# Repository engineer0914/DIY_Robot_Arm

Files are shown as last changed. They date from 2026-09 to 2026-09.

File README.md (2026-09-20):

## 3D 프린팅으로 제작 및 제어하는 DIY 로봇팔 프로젝트

<div align="center">
  <!-- 프로젝트 로고 이미지가 있다면 아래 텍스트(h1) 대신 이미지(img) 태그를 사용하세요 -->
  <h1> 🤖 DIY Robot Arm Project </h1>
  
  <p>저비용 고효율 다관절 로봇팔 자체 제작 및 제어 프로젝트</p>

  <!-- 뱃지 모음 -->
  <p>
    
    
    
    
    
  </p>
</div>

<br>

## 출처

로봇팔: https://www.thingiverse.com/thing:1718984

기어박스: https://www.thingiverse.com/thing:8460

기어: https://www.thingiverse.com/thing:3364646

<div align="center">
  <video src="doc/assembly_vid.mp4" width="600" controls></video>
</div>

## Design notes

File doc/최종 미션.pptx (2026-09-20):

## 그리퍼 형태

- 최종 미션: 지우개를 옮겨라
- 1. 종이컵 -> 지상 녹색 지대내로 이송
- 2. 종이컵은 움직이면 안된다.

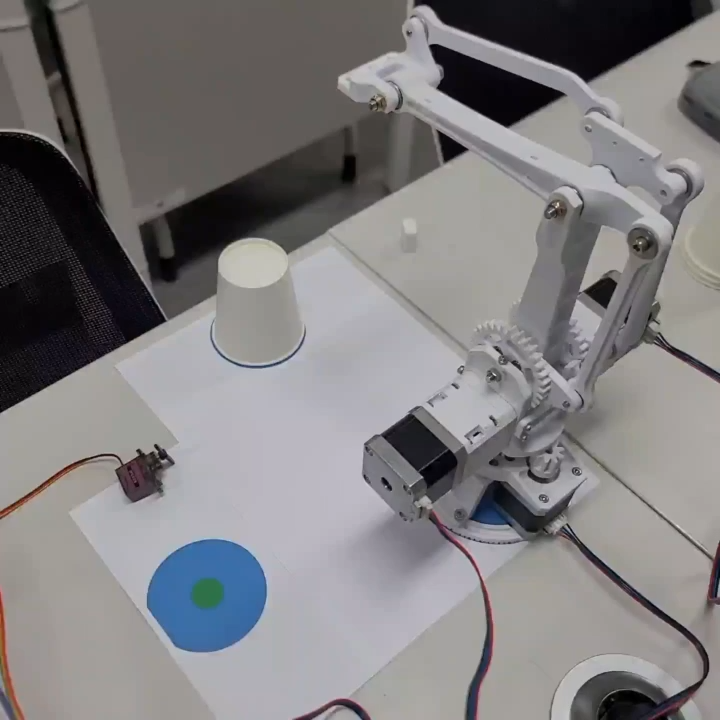
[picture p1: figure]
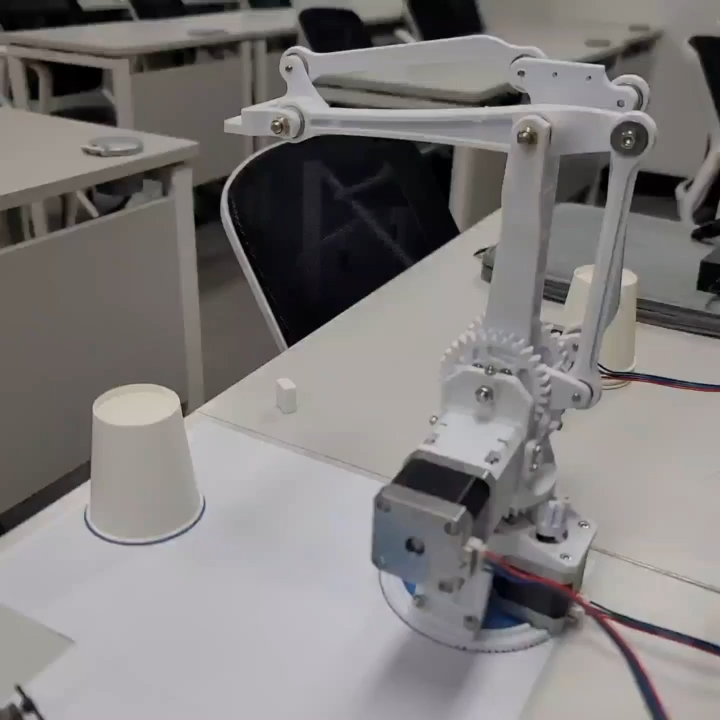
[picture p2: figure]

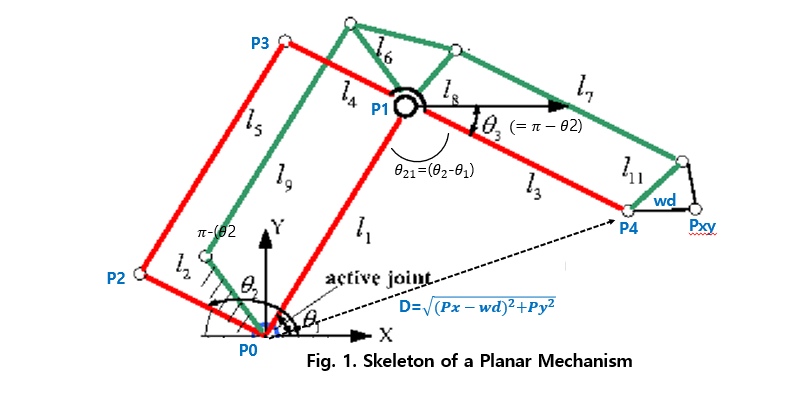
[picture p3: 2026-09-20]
doc/로봇팔 역기구학.png

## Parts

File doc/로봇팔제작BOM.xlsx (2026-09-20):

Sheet: 원본
품명 | 규격 | 수량
프린트 | 바디_접지링 | 1
 | 바디_그라운드 | 1
 | 바디_메인바디 | 1
 | 바디_지지대 | 3
 | 바디_프론트가드 | 1
 | 바디_비하인드가드 | 1
 | 바디_엔드이펙터 | 1
 | 바디_암 | 1
 | 바디_붐 | 1
 | 링크_엔드이펙터컨트롤 | 1
 | 링크_암컨트롤 | 1
 | 링크_암 | 2
 | 링크_붐 | 1
 | 기어_모터_너트(2개 여분) | 5
 | 기어_붐암 | 2
 | 기어_바디 | 1
 | 가이드 | 2
 | 선기어 | 2
 | 케이지 | 2
 | 페이스 | 2
 | 플래닛기어 | 6 | 링크 | 세트 | 표기된 가격
볼트(스텐) | M3(mm)
 | 무두 8 | 10 | https://smartstore.naver.com/boltoutlet/products/3900520395 | 100:1set | 1000
 | 8 | 28 | https://smartstore.naver.com/boltoutlet/products/3567551552 | 100:1set | 1000
 | 12 | 4 |  | 100:1set | 1000
 | 15 | 6 |  | 50:1set | 1000
 | 20 | 8 |  | 50:1set | 1000
 | M4
 | 10 | 6 |  | 50:1set | 1000
 | 15 | 12 |  | 50:1set | 1500
 | M5
 | 45 | 3 |  | 20:1set | 1400
 | 60 | 1 |  | 5:1set | 1600
 | 육각 30 | 2 | https://smartstore.naver.com/boltoutlet/products/4410669973 | 20:1set | 1000
너트(스텐) | M3 | 12 | https://smartstore.naver.com/boltoutlet/products/7063871164 | - | 20
 | M4 | 6 |  | - | 20
 | M3 나일론 | 6 | https://smartstore.naver.com/boltoutlet/products/6990469009 | - | 20
 | M5 나일론 | 4 |  | - | 10
와셔(스텐) | M4 | 12 | https://smartstore.naver.com/boltoutlet/products/3510200845 | 50:1set | 500
 | M5 | 24 |  | 50:1set | 500
 | M4-대형 15 | 10 | https://smartstore.naver.com/boltoutlet/products/3678003117 | 100:1set | 3200
 | M5-대형 15 | 18 |  | 100:1set | 2200
베어링 | 51105(25-42-11) | 1 | https://smartstore.naver.com/allbearing/products/443034914 | - | 3600
베어링 | 695ZZ(5-13-4) | 18 | https://smartstore.naver.com/allbearing/products/415759727 | - | 1500
베어링 | 624ZZ(4-13-5) | 6 |  | - | 1700
베어링 | 683ZZ | 12 |  | - | 1700
베어링 | F695ZZ | 1 | https://www.devicemart.co.kr/goods/view?no=1241387 | - | 3190
스텝모터 | NEMA17 | 3 | https://www.11st.co.kr/products/2475047432?NaPm=ct=l75roit4|ci=f932db0520310e3065b7ae57756678b3c8c51ea6|tr=slct|sn=17703|hk=cb1d047cef103bcc1c7613dbf667e2ce9bfb09c4&utm_term=&utm_campaign=%B3%D7%C0%CC%B9%F6pc_%B0%A1%B0%DD%BA%F1%B1%B3%B1%E2%BA%BB&utm_source=%B3%D7%C0%CC%B9%F6_PC_PCS&utm_medium=%B0%A1%B0%DD%BA%F1%B1%B3 | - | 8700
아두이노 | MEGA | 1 | https://www.devicemart.co.kr/goods/view?no=34405 | - | 58300
아두이노 선 | USB B | 1 | https://www.devicemart.co.kr/goods/view?no=1330154 | - | 990
모터 드라이브 | A4988 | 5(필수3개+여유분2개) | https://www.devicemart.co.kr/goods/view?no=1327610 | - | 1980
드라이브 보드 | A4988 쉴드 보드 | 1 | https://www.devicemart.co.kr/goods/view?no=1361492 | - | 2200
점퍼캡 | 2.54 | 9 | https://www.devicemart.co.kr/goods/view?no=1077104 | 5:1set | 220
파워서플라이 | 12V | 1 | https://www.devicemart.co.kr/goods/view?no=21792 | - | 18700
배럴잭 | - | 1 | https://www.devicemart.co.kr/goods/view?no=1065012 | - | 2420
핀헤더 | - | 2 | https://www.devicemart.co.kr/goods/view?no=20009 | 40:1set | 275
푸시락 버튼 | - | 1 | https://www.devicemart.co.kr/goods/view?no=10826175 | - | 2530
8버튼 | - | 1 | https://www.devicemart.co.kr/goods/view?no=1384067 | - | 7150
전선 | 암수 | 10가닥 | https://www.devicemart.co.kr/goods/view?no=1321195 | 40:1set(가닥) | 935 | 몇 개 남은가 | 필수 부품인가
배송비 | 디바이스마트 |  |  |  | 2700
 | 볼트 |  |  |  | 2500
 | 베어링 |  |  |  | 3500

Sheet: 10단위 올림표
품명 | 규격 | 수량
프린트 | 바디_접지링 | 1
 | 바디_그라운드 | 1
 | 바디_메인바디 | 1
 | 바디_지지대 | 3
 | 바디_프론트가드 | 1
 | 바디_비하인드가드 | 1
 | 바디_엔드이펙터 | 1
 | 바디_암 | 1
 | 바디_붐 | 1
 | 링크_엔드이펙터컨트롤 | 1
 | 링크_암컨트롤 | 1
 | 링크_암 | 1
 | 링크_붐 | 2
 | 기어_모터_너트(2개 여분) | 5
 | 기어_붐암 | 2
 | 기어_바디 | 1
 | 가이드 | 2
 | 선기어 | 2
 | 케이지 | 2
 | 페이스 | 2
 | 플래닛기어 | 6 | 링크 | 세트 | 표기된 가격
볼트(스텐) | M3(mm)
 | 무두 8 | 10 | https://smartstore.naver.com/boltoutlet/products/3900520395 | 100:1set | 1000
 | 8 | 30 | https://smartstore.naver.com/boltoutlet/products/3567551552 | 100:1set | 1000
 | 12 | 10 |  | 100:1set | 1000
 | 15 | 10 |  | 50:1set | 1000
 | 20 | 10 |  | 50:1set | 1000
 | M4
 | 10 | 10 |  | 50:1set | 1000
 | 15 | 20 |  | 50:1set | 1500
 | M5
 | 45 | 10 |  | 20:1set | 1400
 | 60 | 10 |  | 5:1set | 1600
 | 육각 30 | 10 | https://smartstore.naver.com/boltoutlet/products/4410669973 | 20:1set | 1000
너트(스텐) | M3 | 30 | https://smartstore.naver.com/boltoutlet/products/7063871164 | - | 20
 | M4 | 10 |  | - | 20
 | M3 나일론 | 10 | https://smartstore.naver.com/boltoutlet/products/6990469009 | - | 20
 | M5 나일론 | 10 |  | - | 10
와셔(스텐) | M4 | 20 | https://smartstore.naver.com/boltoutlet/products/3510200845 | 50:1set | 500
 | M5 | 30 |  | 50:1set | 500
 | M4-대형 15 | 10 | https://smartstore.naver.com/boltoutlet/products/3678003117 | 100:1set | 3200
 | M5-대형 15 | 20 |  | 100:1set | 2200
베어링 | 51105(25-42-11) | 1 | https://smartstore.naver.com/allbearing/products/443034914 | - | 3600
베어링 | 695ZZ(5-13-4) | 18 | https://smartstore.naver.com/allbearing/products/415759727 | - | 1500
베어링 | 624ZZ(4-13-5) | 6 |  | - | 1700
베어링 | 683ZZ | 12 |  | - | 1700
베어링 | F695ZZ | 1 | https://www.devicemart.co.kr/goods/view?no=1241387 | - | 3190
스텝모터 | NEMA17 | 3 | https://www.11st.co.kr/products/2475047432?NaPm=ct=l75roit4|ci=f932db0520310e3065b7ae57756678b3c8c51ea6|tr=slct|sn=17703|hk=cb1d047cef103bcc1c7613dbf667e2ce9bfb09c4&utm_term=&utm_campaign=%B3%D7%C0%CC%B9%F6pc_%B0%A1%B0%DD%BA%F1%B1%B3%B1%E2%BA%BB&utm_source=%B3%D7%C0%CC%B9%F6_PC_PCS&utm_medium=%B0%A1%B0%DD%BA%F1%B1%B3 | - | 8700
아두이노 | MEGA | 1 | https://www.devicemart.co.kr/goods/view?no=34405 | - | 58300
아두이노 선 | USB B | 1 | https://www.devicemart.co.kr/goods/view?no=1330154 | - | 990
모터 드라이브 | A4988 | 5 | https://www.devicemart.co.kr/goods/view?no=1327610 | - | 1980
드라이브 보드 | A4988 쉴드 보드 | 1 | https://www.devicemart.co.kr/goods/view?no=1361492 | - | 2200
점퍼캡 | 2.54 | 10 | https://www.devicemart.co.kr/goods/view?no=1077104 | 5:1set | 220
파워서플라이 | 12V | 1 | https://www.devicemart.co.kr/goods/view?no=21792 | - | 18700
배럴잭 | - | 1 | https://www.devicemart.co.kr/goods/view?no=1065012 | - | 2420
핀헤더 | - | 2 | https://www.devicemart.co.kr/goods/view?no=20009 | 40:1set | 275
푸시락 버튼 | - | 1 | https://www.devicemart.co.kr/goods/view?no=10826175 | - | 2530
8버튼 | - | 1 | https://www.devicemart.co.kr/goods/view?no=1384067 | - | 7150
전선 | 암수 | 13(가닥) | https://www.devicemart.co.kr/goods/view?no=1321195 | 40:1set(가닥) | 935
배송비 | 디바이스마트 |  |  |  | 2700
 | 볼트 |  |  |  | 2500
 | 베어링 |  |  |  | 3500

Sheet: 25년 가을 비교과 부품
비고 | 품명 | 규격 | 수량 | 5세트시 낱개 | 최종 구매 개수 | 링크 | 세트 | 부가세포함 1개 가격 | 총액 | 합산 금액 | 해외여부 | 활성화 | -
볼트 (SCM or 스텐) | M3(mm) |  |  |  |  |  |  |  |  |  |  | 0
 | 무두 8 |  | 10 | 50 | 50 | https://www.devicemart.co.kr/goods/view?no=10913620 | 10 | 33 | 330 | 1650 |  | 1
 | 8 |  | 30 | 150 | 150 | https://www.devicemart.co.kr/goods/view?no=34295 | 10 | 66 | 1980 | 9900 |  | 1
 | 12 |  | 10 | 50 | 50 | https://www.devicemart.co.kr/goods/view?no=10915194 | 10 | 66 | 660 | 3300 |  | 1
 | 15 |  | 10 | 50 | 50 | https://www.devicemart.co.kr/goods/view?no=10913623 | 10 | 44 | 440 | 2200 |  | 1 |  | 1414880 | 총액
 | 20 |  | 10 | 50 | 50 | https://www.devicemart.co.kr/goods/view?no=34536 | 10 | 66 | 660 | 3300 |  | 1
 | M4 |  |  | 0
 | 10 |  | 10 | 50 | 50 | https://www.devicemart.co.kr/goods/view?no=34496 | 10 | 55 | 550 | 2750 |  | 1 |  | 1500000 | 상한가
 | 15 |  | 20 | 100 | 100 | https://www.devicemart.co.kr/goods/view?no=34537 | 10 | 77 | 1540 | 7700 |  | 1
 | M5 |  |  | 0 |  |  |  |  |  |  |  | 1
 | 45 |  | 10 | 50 | 50 | https://www.devicemart.co.kr/goods/view?no=10915237 | 10 | 220 | 2200 | 11000 |  | 1
 | 60 |  | 10 | 50 | 50 | https://www.devicemart.co.kr/goods/view?no=10913873 | 10 | 320 | 3200 | 16000 |  | 1
 |  |  |  | 0
너트 (SCM or 스텐) | M3 |  | 30 | 150 | 150 | https://www.devicemart.co.kr/goods/view?no=34324 | 10 | 11 | 330 | 1650 |  | 1
 | M4 |  | 10 | 50 | 50 | https://www.devicemart.co.kr/goods/view?no=10893597 | 10 | 77 | 770 | 3850 |  | 1 |  | 육각 볼트 추가 배분 필요, 푸시락 버튼, 아두이노 쉴드
 | M3 나일론 |  | 10 | 50 | 50 | https://www.devicemart.co.kr/goods/view?no=34328 | 10 | 15.4 | 154 | 770 |  | 1
 | M5 나일론 |  | 10 | 50 | 50 | https://www.devicemart.co.kr/goods/view?no=34330 | 10 | 22 | 220 | 1100 |  | 1
와셔 (SCM or 스텐) | M4 |  | 20 | 100 | 2 | https://smartstore.naver.com/boltoutlet/products/3510200845 | 50:1set | 500 | 10000 | 1000 |  | 1
 | M5 |  | 30 | 150 | 3 |  | 50:1set | 500 | 15000 | 1500 |  | 1
 | M4-대형 15 |  | 10 | 50 | 1 | https://smartstore.naver.com/boltoutlet/products/3678003117 | 100:1set | 2200 | 22000 | 2200 |  | 1
 | M5-대형 15 |  | 20 | 100 | 1 |  | 100:1set | 2200 | 44000 | 2200 |  | 1
베어링 | 51105(25-42-11) |  | 1 | 5 | 5 | https://www.devicemart.co.kr/goods/view?no=1278300 | - | 4180 | 4180 | 20900 |  | 1
 | 695ZZ(5-13-4) |  | 18 | 90 | 90 | https://www.devicemart.co.kr/goods/view?no=1241341 | - | 1760 | 31680 | 158400 |  | 1
 | 624ZZ(4-13-5) |  | 6 | 30 | 30 | https://www.devicemart.co.kr/goods/view?no=1241334 | - | 1980 | 11880 | 59400 |  | 1
 | 683ZZ |  | 12 | 60 | 60 | https://www.devicemart.co.kr/goods/view?no=1241322 | - | 2090 | 25080 | 125400 |  | 1
 | F695ZZ |  | 1 | 5 | 5 | https://www.devicemart.co.kr/goods/view?no=1241387 | - | 3190 | 3190 | 15950 |  | 1
 |  |  |  | 0
 |  |  |  | 0
공구 | 롱노우즈 |  | 1 | 5 | 5 | https://www.devicemart.co.kr/goods/view?no=10991277 | - | 6160 | 6160 | 30800 |  | 1
 | 볼렌치 |  | 1 | 5 | 5 | https://www.devicemart.co.kr/goods/view?no=10991327 | - | 7700 | 7700 | 38500 |  | 1
 | 전동 드라이버 |  | 1 | 5 | 5 | https://www.devicemart.co.kr/goods/view?no=15018718 | - | 45430 | 45430 | 227150 |  | 1
스텝모터 | NEMA17 |  | 3 | 15 | 15 | https://www.11st.co.kr/products/2475047432?NaPm=ct=l75roit4|ci=f932db0520310e3065b7ae57756678b3c8c51ea6|tr=slct|sn=17703|hk=cb1d047cef103bcc1c7613dbf667e2ce9bfb09c4&utm_term=&utm_campaign=%B3%D7%C0%CC%B9%F6pc_%B0%A1%B0%DD%BA%F1%B1%B3%B1%E2%BA%BB&utm_source=%B3%D7%C0%CC%B9%F6_PC_PCS&utm_medium=%B0%A1%B0%DD%BA%F1%B1%B3 | - | 8700 | 26100 | 130500 |  | 1
아두이노 | MEGA |  | 1 | 5 | 5 | https://www.devicemart.co.kr/goods/view?no=34405 | - | 59400 | 59400 | 297000 |  | 1
아두이노 USB 선 | USB B |  | 1 | 5 | 5 | https://www.devicemart.co.kr/goods/view?no=1063725 | - | 1870 | 1870 | 9350 |  | 1
모터 드라이브 | A4988 |  | 4 | 20 | 20 | https://www.devicemart.co.kr/goods/view?no=1327610 | - | 1980 | 7920 | 39600 |  | 1
드라이브 보드 | A4988 쉴드 보드 |  | 1 | 5 | 5 | https://www.devicemart.co.kr/goods/view?no=1361492 | - | 2200 | 2200 | 11000 |  | 1
점퍼캡 | 2.54 |  | 10 | 50 | 50 | https://www.devicemart.co.kr/goods/view?no=1077104 | 5:1set | 44 | 440 | 2200 |  | 1
파워서플라이 | 12V |  | 1 | 5 | 5 | https://www.devicemart.co.kr/goods/view?no=21792 | - | 20900 | 20900 | 104500 |  | 1
배럴잭 | - |  | 1 | 5 | 5 | https://www.devicemart.co.kr/goods/view?no=1065012 | - | 2420 | 2420 | 12100 |  | 1
8버튼 | - |  | 1 | 5 | 1 | https://www.devicemart.co.kr/goods/view?no=1384067 | - | 7150 | 7150 | 7150 |  | 1
전선 | 암수 |  | 1 | 5 | 3 | https://www.devicemart.co.kr/goods/view?no=1321195 | 40:1set(가닥) | 935 | 935 | 2805 |  | 1
 | 암암 |  | 1 | 5 | 3 | https://www.devicemart.co.kr/goods/view?no=1321196 | 40:1set(가닥) | 935 | 935 | 2805 |  | 1
 | 수수 |  | 1 | 5 | 3 | https://www.devicemart.co.kr/goods/view?no=1321192 | 40:1set(가닥) | 935 | 935 | 2805 |  | 1
핀헤더 | - |  | 1 | 5 | 1 | https://www.devicemart.co.kr/goods/view?no=20009 | 40:1set | 275 | 275 | 275 |  | 1
스텝모터 연결선 여분 |  |  | 3 | 15 | 15 | https://www.devicemart.co.kr/goods/view?no=10893116 | - | 1100 | 3300 | 16500 |  | 1
서보모터 | mg90 |  | 1 | 5 | 6 | https://www.devicemart.co.kr/goods/view?no=1313389 | - | 4620 | 4620 | 27720 |  | 1

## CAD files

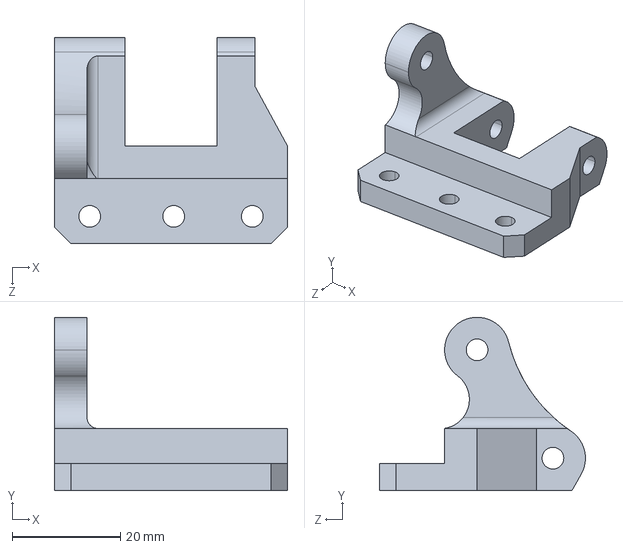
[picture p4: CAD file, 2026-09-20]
CAD/바디_엔드이펙터.STEP
43.0 x 32.0 x 38.0 mm

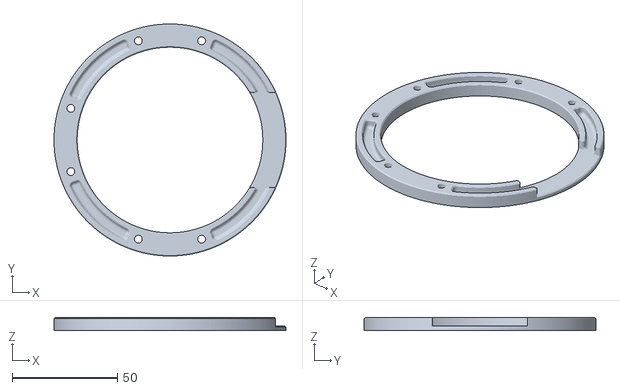
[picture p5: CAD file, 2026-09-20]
PrintFile/[ARM][1pcs] baseRing 바디_접지링.stl
110.0 x 110.0 x 6.00

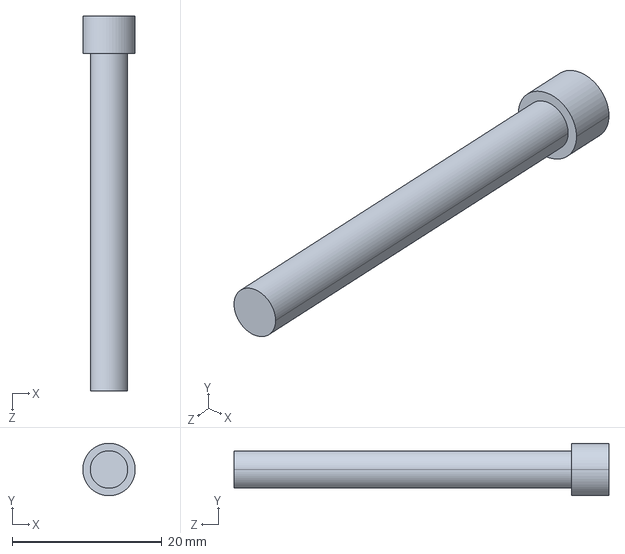
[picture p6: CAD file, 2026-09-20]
CAD/볼트 m5 45.STEP
7.00 x 7.00 x 50.0 mm

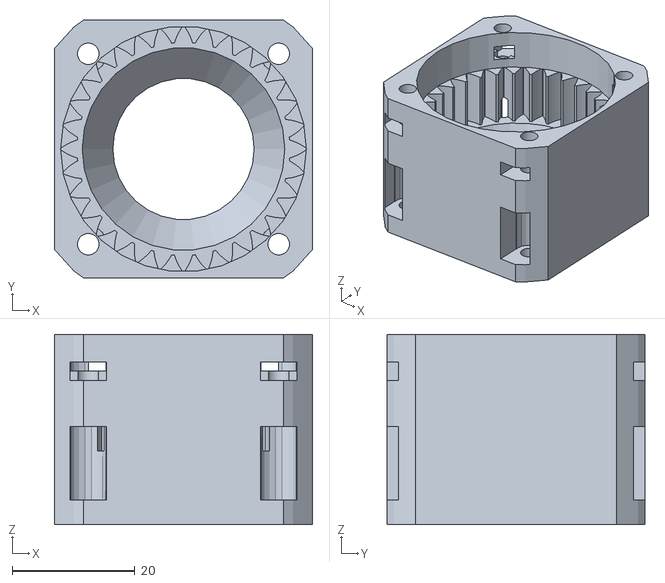
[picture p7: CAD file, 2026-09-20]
PrintFile/[REDUCER][2pcs] housing 케이지.stl
42.0 x 42.0 x 31.0

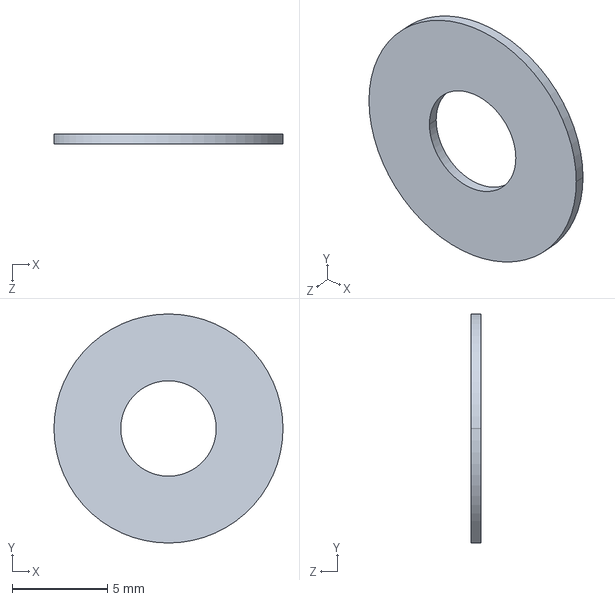
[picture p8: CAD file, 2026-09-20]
CAD/와셔 m5.STEP
12.0 x 12.0 x 0.5 mm

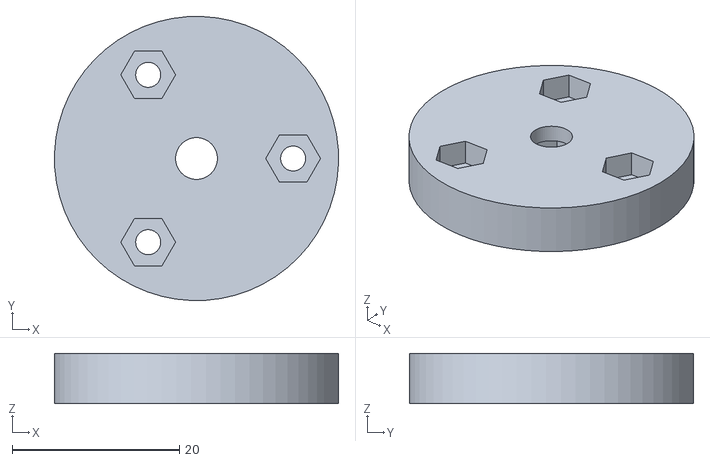
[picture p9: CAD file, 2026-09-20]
PrintFile/[REDUCER][2pcs] carrier 가이드.stl
34.0 x 34.0 x 6.00

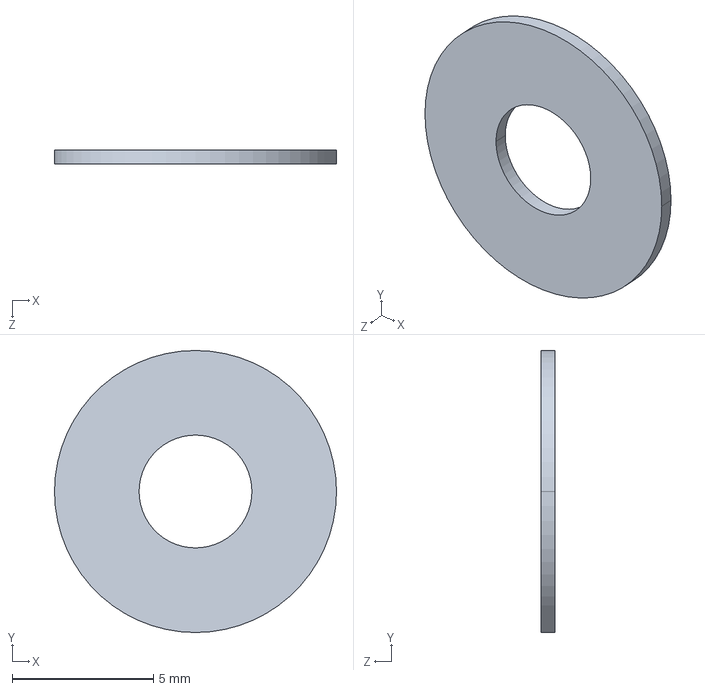
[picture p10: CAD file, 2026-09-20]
CAD/와셔 m4.STEP
10.0 x 10.0 x 0.5 mm

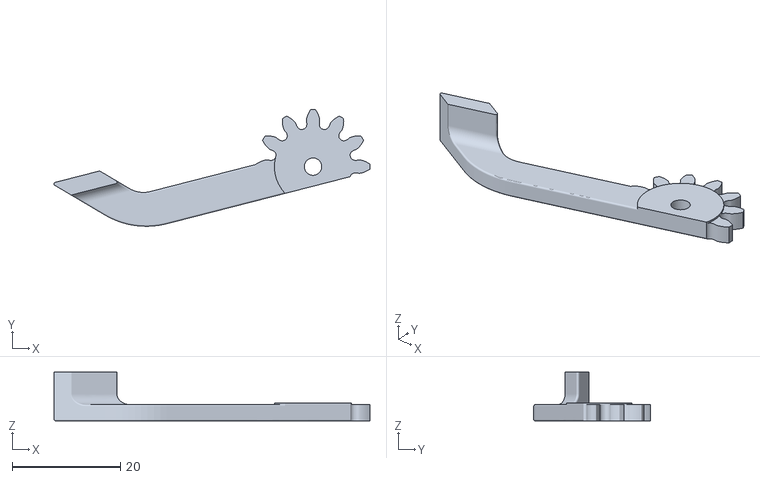
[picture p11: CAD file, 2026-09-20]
PrintFile/[sGripper][1pcs]EBAmk2_017_claw_finger_sx.STL
58.3 x 21.5 x 9.00

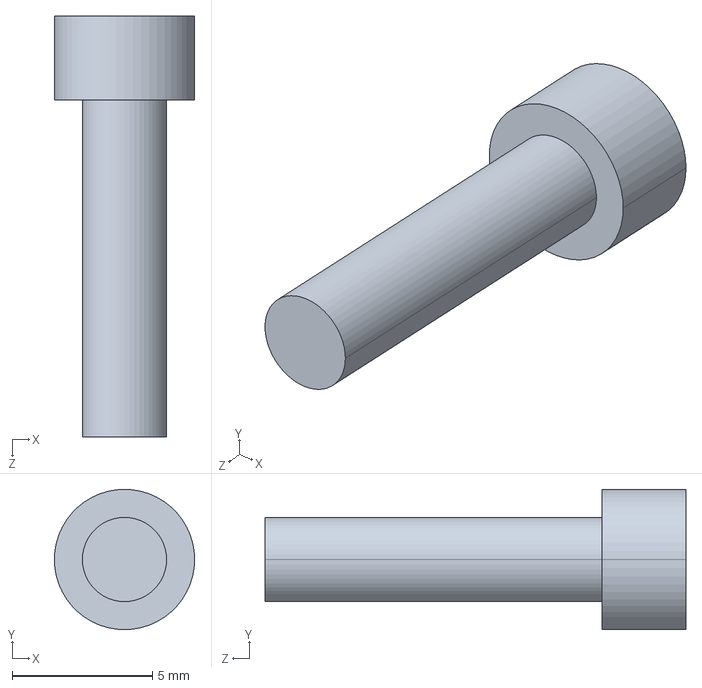
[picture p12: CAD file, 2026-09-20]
CAD/볼트 m3 12.STEP
5.00 x 5.00 x 15.0 mm

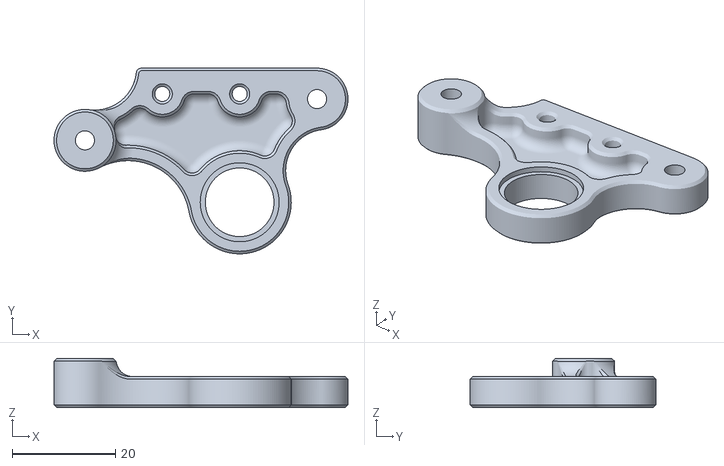
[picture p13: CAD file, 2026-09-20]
PrintFile/[ARM][1pcs] triplate 링크_엔드이펙터컨트롤.stl
57.0 x 36.0 x 9.50

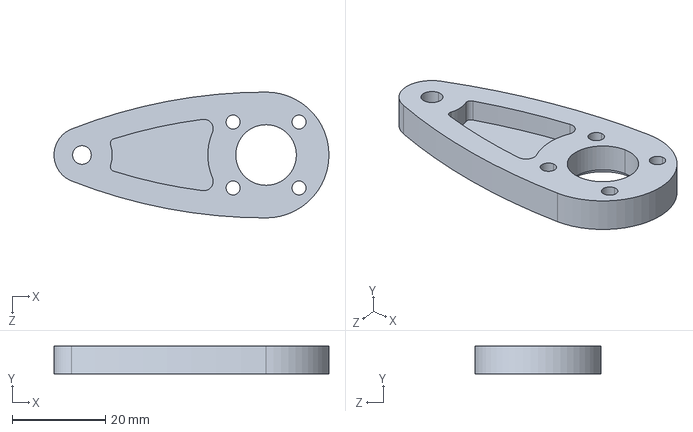
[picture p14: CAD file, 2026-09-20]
CAD/링크_암컨트롤.STEP
59.0 x 6.00 x 27.0 mm

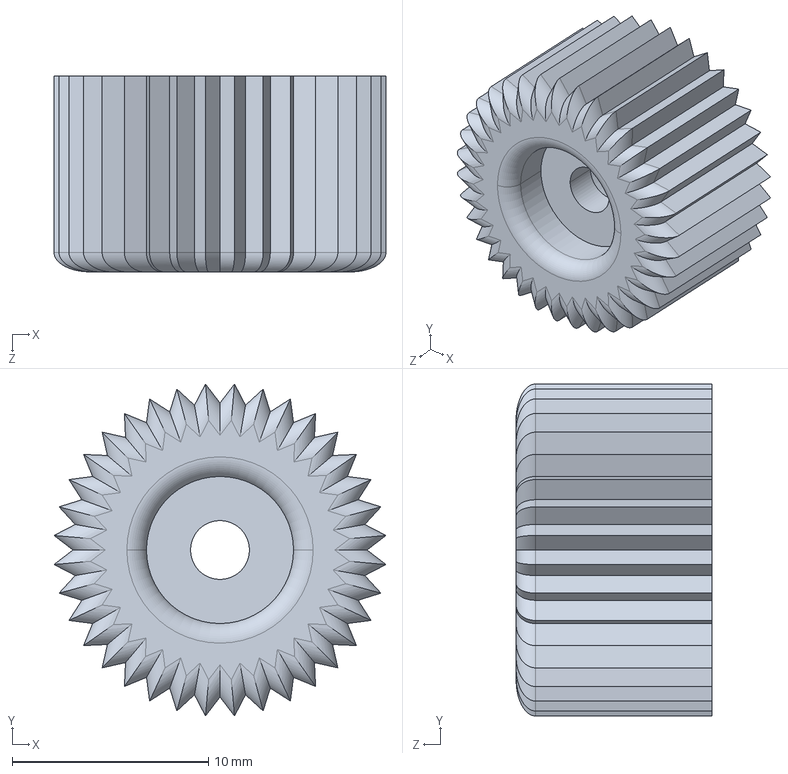
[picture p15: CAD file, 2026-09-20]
CAD/플래닛기어.STEP
16.9 x 16.9 x 10.0 mm

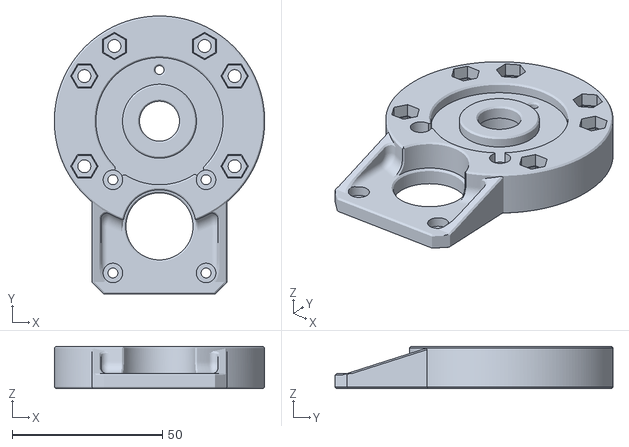
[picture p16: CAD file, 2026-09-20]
PrintFile/[ARM][1pcs] socket 바디_그라운드.stl
70.0 x 92.5 x 14.0

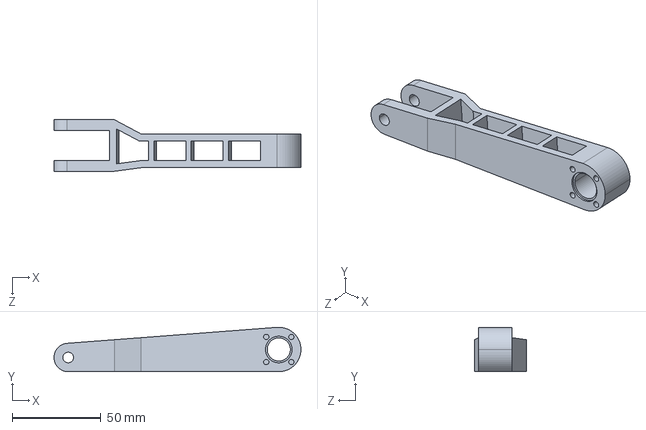
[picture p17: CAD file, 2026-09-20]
CAD/바디_붐.STEP
139.0 x 25.0 x 29.0 mm

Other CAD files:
PrintFile/[ARM][1pcs] GearRotate_0.01mmTolerance 기어_바디.stl
CAD/바디_접지링.STEP
PrintFile/[REDUCER][6pcs] planet 플래닛기어.stl
CAD/바디_메인바디.STEP
CAD/683zz 베어링.STEP
CAD/가이드.STEP
CAD/기어_모터.STEP
CAD/기어_바디.STEP
CAD/기어_붐암.STEP
CAD/나일론 m3 너트.STEP
CAD/너트 m3.STEP
CAD/너트 m4.STEP
CAD/너트 m5 나일론.STEP
CAD/링크_붐.STEP
CAD/링크_암.STEP
CAD/링크_엔드이펙터컨트롤.STEP
CAD/모터.STEP
CAD/무두나사 m3 8.STEP
CAD/바디_그라운드.STEP
CAD/바디_비하인드가드.STEP
CAD/바디_암.STEP
CAD/바디_지지대.STEP
CAD/바디_프론트가드.STEP
CAD/베어링 m4.STEP
CAD/베어링 m5.STEP
CAD/베어링 m5f.STEP
CAD/베어링 베이스.STEP
CAD/볼트 m3 15.STEP
CAD/볼트 m3 20.STEP
CAD/볼트 m3 8.STEP
CAD/볼트 m4 10.STEP
CAD/볼트 m4 15.STEP
CAD/볼트 m5 60.STEP
CAD/선기어.STEP
CAD/엔드이펙터 마커.STEP
CAD/와셔 m4 대형.STEP
CAD/와셔 m5 대형.STEP
CAD/육각볼트 m5 30.STEP
CAD/케이지.STEP
CAD/페이스.STEP
PrintFile/[ARM][1pcs] base_w_hole 바디_메인바디.stl
PrintFile/[ARM][1pcs] lever 링크_암컨트롤.stl
PrintFile/[ARM][1pcs] lowerShank 바디_붐.stl
PrintFile/[ARM][1pcs] pleuel 링크_붐.stl
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

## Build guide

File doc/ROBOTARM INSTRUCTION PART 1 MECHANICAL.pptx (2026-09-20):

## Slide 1

ROBOT ARM INSTRUCTION
PART.1 - MECHANICAL

Prof. Wooyong Kim
Assistant. Dongsik Park
Department of Biomedical & Robotics Engineering,
Incheon National University

Summer, 2026

## Table of Contents

  1. List Of Part
  2. Building Instruction

## 1. List Of Part

3D Print

Part name | Number
바디_접지링 | 1
바디_그라운드 | 1
바디_메인바디 | 1
바디_지지대 | 3
바디_프론트가드 | 1
바디_비하인드가드 | 1
바디_엔드이펙터 | 1
바디_암 | 1
바디_붐 | 1
링크_엔드이펙터컨트롤 | 1
링크_암컨트롤 | 1
링크_암 | 1
링크_붐 | 2
기어_모터_너트(2개 여분) | 5
기어_붐암 | 2
기어_바디 | 1
가이드 | 2
선기어 | 2
케이지 | 2
페이스 | 2
플래닛기어 | 6

Mechanical Material

(Need) hex key(육각렌치) – 1.5, 3, 4, 5 mm

Part name | Number
M3 8 무두 | 10
M3 8 | 28
M3 12 | 4
M3 15 | 6
M3 20 | 8
M4 10 | 6
M4 15 | 12
M5 45 | 3
M5 60 | 1
M5 30 육각 | 2
M3 너트 | 22
M4 너트 | 6
M3 나일론 너트 | 6
M5 나일론 너트 | 4
M4 와셔 | 12
M5 와셔 | 24
M4 와셔 대형 | 8
M5 와셔 대형 | 20
베어링 51105(25-42-11) | 1
베어링 695ZZ(5-13-4) | 18
베어링 624ZZ(4-13-5) | 6
베어링 683ZZ | 12
베어링 F695ZZ | 1

Circuit Material

(Need) Phillips screwdriver (십자드라이버)

Part name | Number
스텝모터 | 3
아두이노 메가 | 1
A4988 드라이버 | 3
드라이브 보드 | 1
점퍼캡 | 9
파워서플라이 | 1
배럴잭 | 1
핀헤더 | 2
푸시락 버튼 | 1
8버튼 | 1
전선 | 13

## 1. List Of Part

3D Print & Body parts look

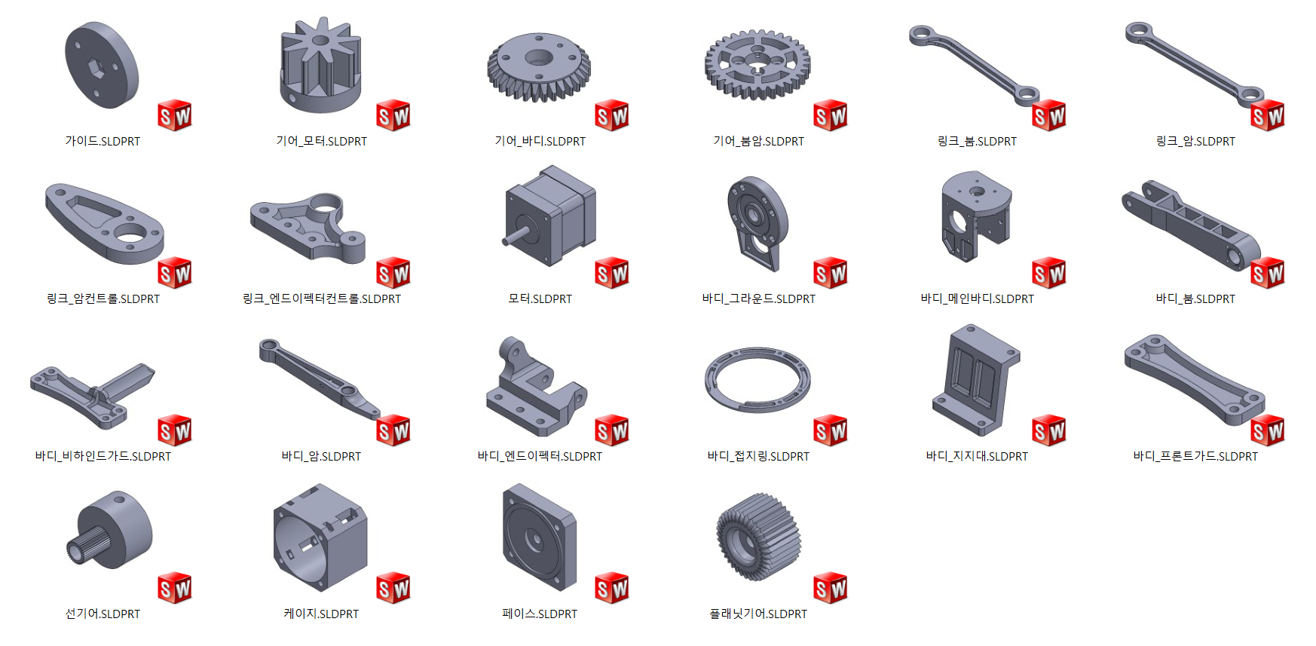
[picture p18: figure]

가이드

기어_모터_너트

기어_바디

기어_붐암

링크_암

링크_붐

링크_암컨트롤

링크_엔드이펙터컨트롤

스텝모터

바디_그라운드

바디_메인바디

바디_붐

바디_비하인드가드

바디_암

바디_엔드이펙터

바디_접지링

바디_지지대

바디_프론트가드

선기어

케이지

페이스

플래닛기어

## 2. Building Instruction

Base

Part name | Count
M4 10mm | 6
M4 15mm | 6
M4 너트 | 6

Required Parts

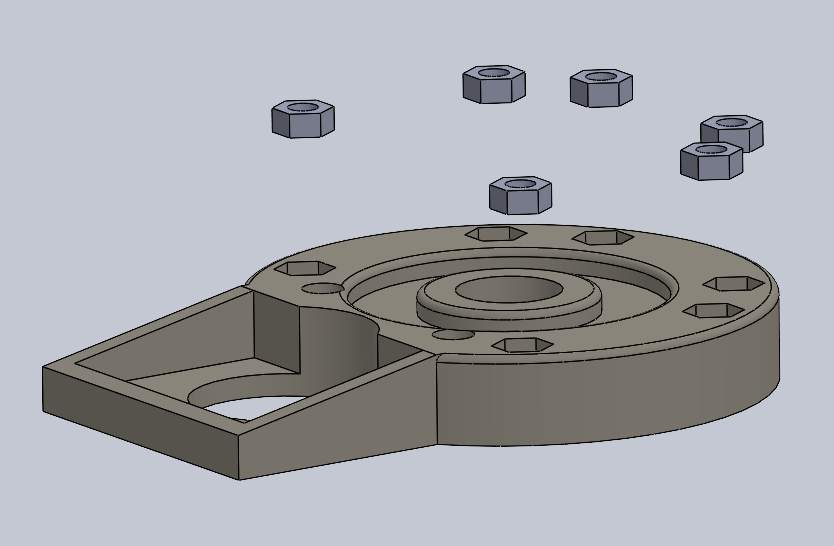
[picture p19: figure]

10mm

15mm

## 2. Building Instruction

Base

Part name | Count
M3 8mm (무두) | 2
M3 8mm | 4
M3 너트 | 2
베어링 51105 | 1

Required Parts

무두 나사

베어링

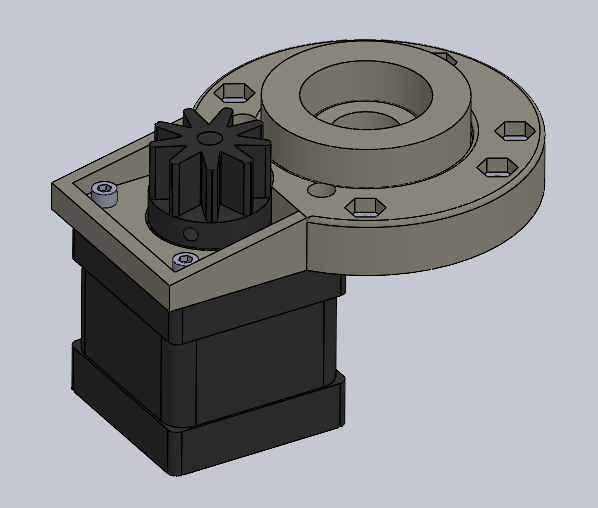
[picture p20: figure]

## 2. Building Instruction

Base

Part name | Count
M5 45mm | 1
M3 너트 | 4
M5 너트 (나일론) | 1
M5 와셔 (대형) | 4
베어링 F695ZZ | 1

Required Parts

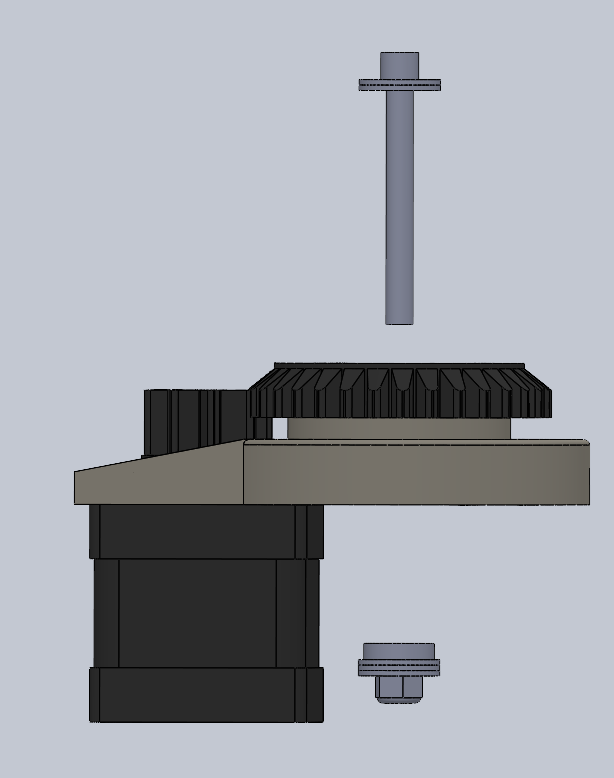
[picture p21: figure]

대형 와셔 X 2

베어링
대형 와셔 X 2
나일론 너트

## 2. Building Instruction

Base

## 2. Building Instruction

GearReducer

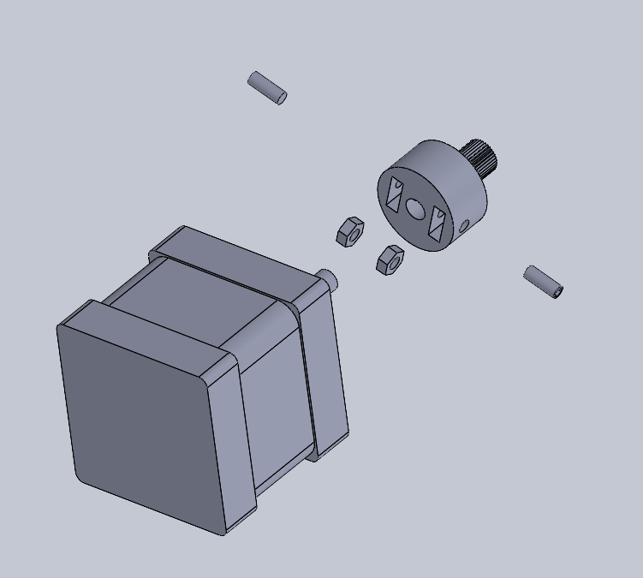
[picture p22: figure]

Part name | Count
M3 8mm (무두) | 2
M3 너트 | 2

Required Parts

무두 나사

## 2. Building Instruction

GearReducer

Part name | Count
M3 15mm | 3
M5 30mm (육각) | 1
M3 너트 (나일론) | 3
베어링 683ZZ (M3) | 6

Required Parts

베어링

15mm

나일론 너트

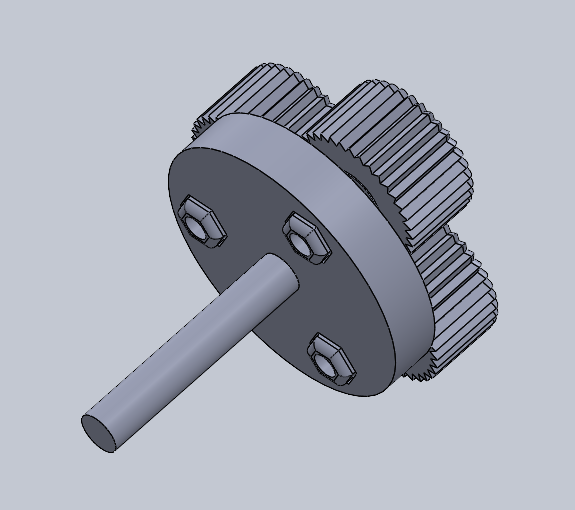
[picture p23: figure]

## 2. Building Instruction

GearReducer

Part name | Count
M3 8mm | 4
베어링 695ZZ (M5) | 2

Required Parts

베어링

베어링

## 2. Building Instruction

GearReducer

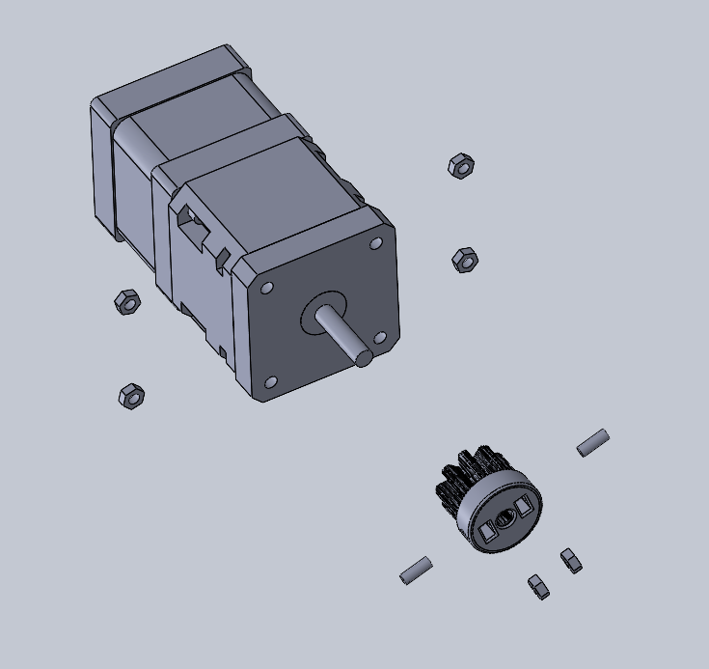
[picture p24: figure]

Part name | Count
M3 8mm (무두) | 2
M3 너트 | 6

Required Parts

무두 나사

## 2. Building Instruction

Body

Part name | Count
M3 20mm | 8

Required Parts

## 2. Building Instruction

Body

Part name | Count
M3 12mm | 4

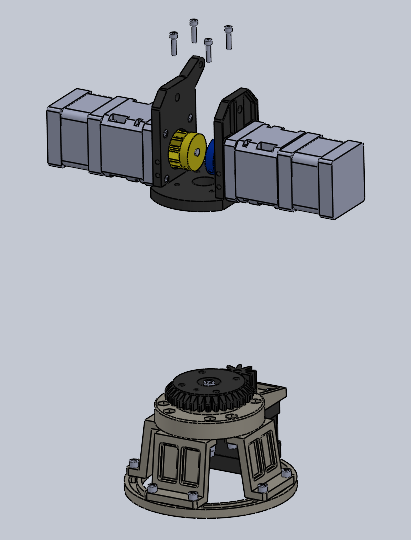
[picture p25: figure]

## 2. Building Instruction

Arm

Part name | Count
M5 45mm | 1
M5 너트 (나일론) | 1
M5 와셔 | 2
M5 와셔 (대형) | 4
베어링 695ZZ (M5) | 3

Required Parts

대형 와셔

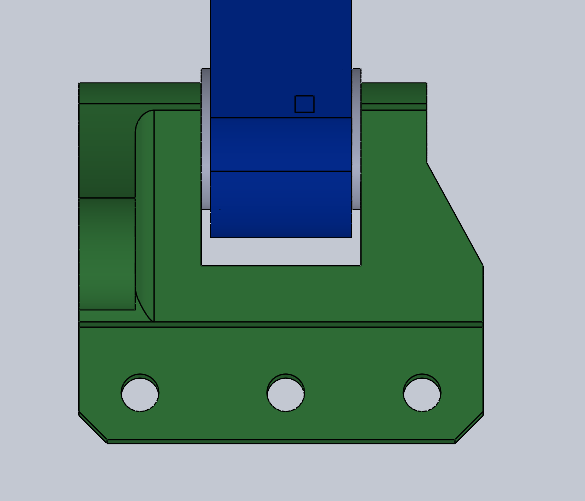
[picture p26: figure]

와셔

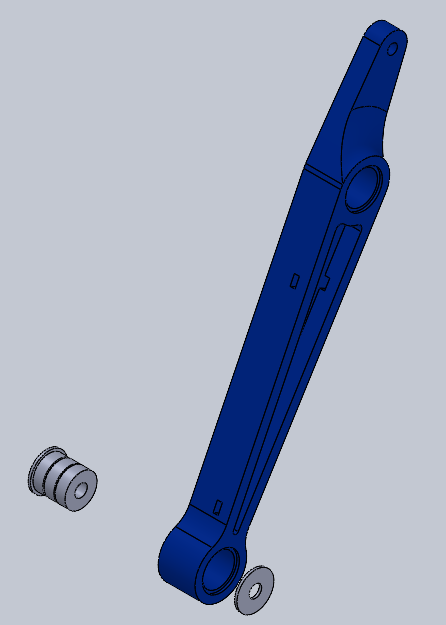
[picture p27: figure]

## 2. Building Instruction

Arm

Part name | Count
M5 45mm | 1
M5 와셔 | 2
M5 와셔 (대형) | 5
베어링 695ZZ (M5) | 3

Required Parts

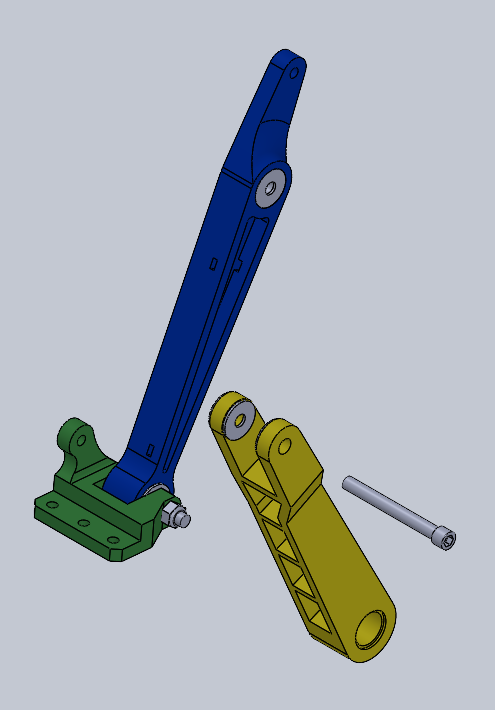
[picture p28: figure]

위치별 대형 와셔 개수: 2 2 1

와셔

## 2. Building Instruction

Arm

Part name | Count
M5 45mm | 1
M5 너트 (나일론) | 1
M5 와셔 | 4
M5 와셔 (대형) | 1
베어링 695ZZ (M5) | 1

Required Parts

대형 와셔

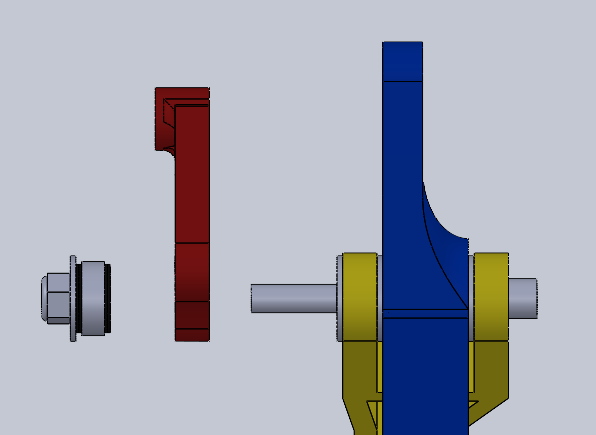
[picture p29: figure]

와셔 X2

## 2. Building Instruction

Arm

Part name | Count
M4 15mm | 2
M4 와셔 | 4
M4 와셔 (대형) | 4
베어링 624ZZ (M4) | 2

Required Parts

대형 와셔

와셔

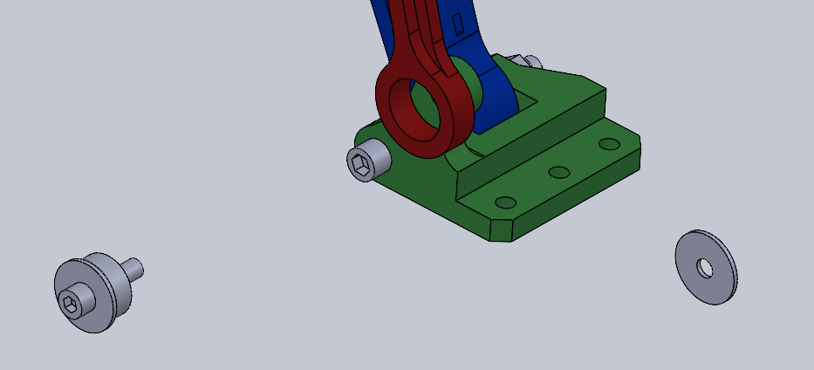
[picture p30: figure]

## 2. Building Instruction

Arm

Part name | Count
M4 15mm | 1
M4 와셔 | 2
M4 와셔 (대형) | 2
베어링 624ZZ (M4) | 1

Required Parts

대형 와셔

와셔

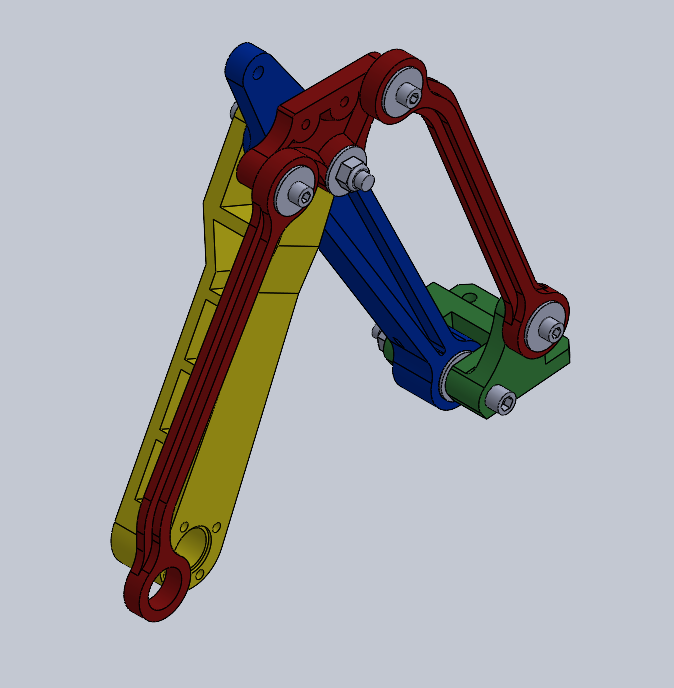
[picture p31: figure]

## 2. Building Instruction

Arm

Part name | Count
M4 15mm | 1
M4 와셔 | 2
M4 와셔 (대형) | 2
베어링 624ZZ (M4) | 1

Required Parts

대형 와셔

와셔

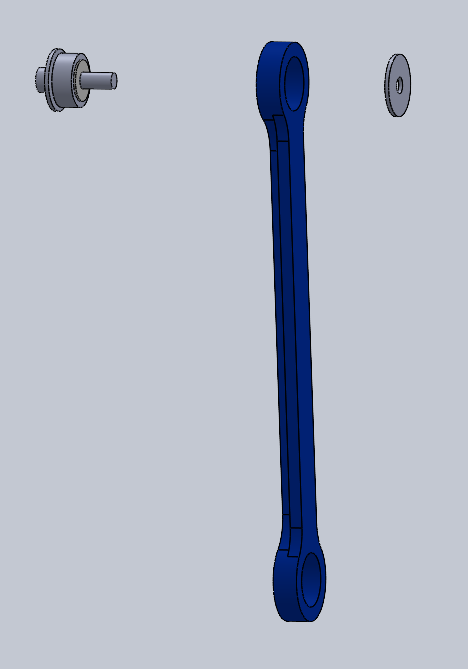
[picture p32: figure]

## 2. Building Instruction

Arm

Part name | Count
M5 와셔 | 2
M5 와셔 (대형) | 2
베어링 695ZZ (M5) | 4

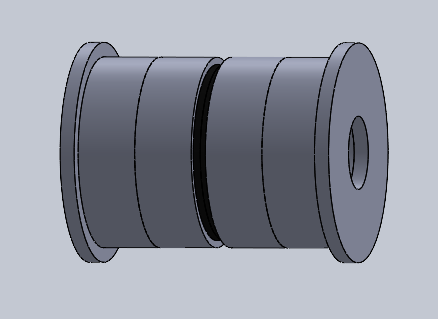
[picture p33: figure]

대형 와셔

와셔 X2

## 2. Building Instruction

Part name | Count
M3 8mm | 8
M5 와셔 | 14 (9/5)
M5 와셔 (대형) | 2
베어링 695ZZ (M5) | 3

Required Parts

Arm

대형 와셔

위치별 와셔 개수: 1 2 4 2

위치별 와셔 개수: 2 2 1

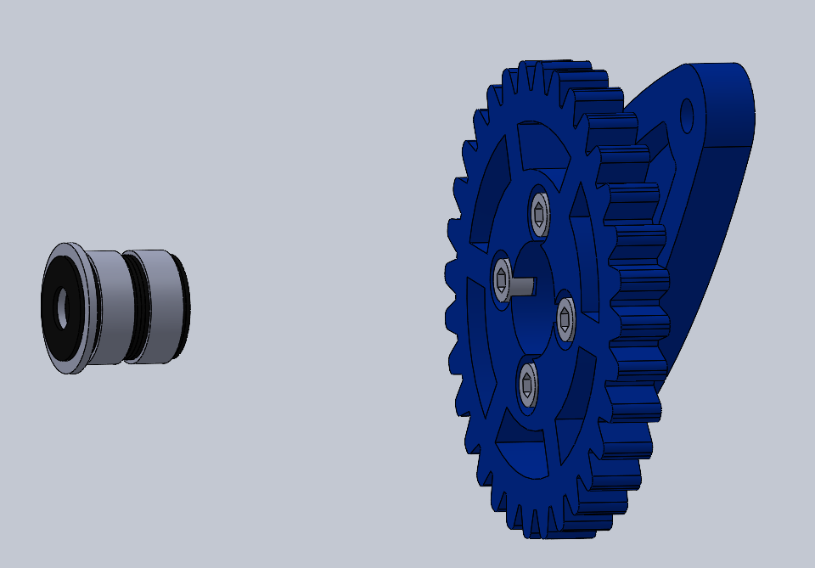
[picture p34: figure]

## 2. Building Instruction

Arm

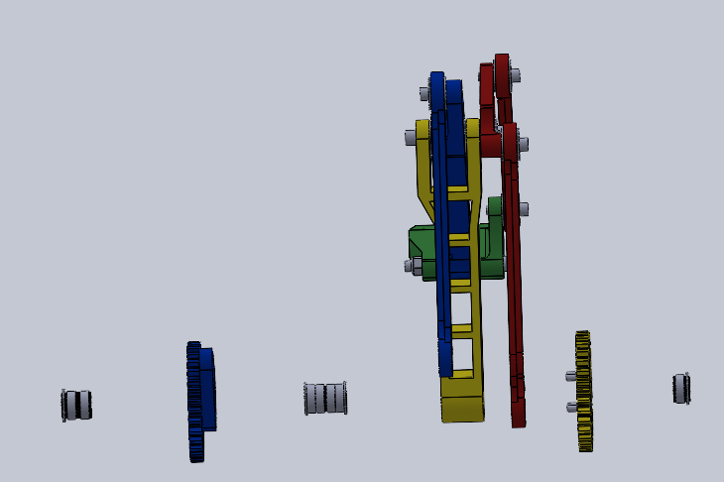
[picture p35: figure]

## 2. Building Instruction

Final assembly

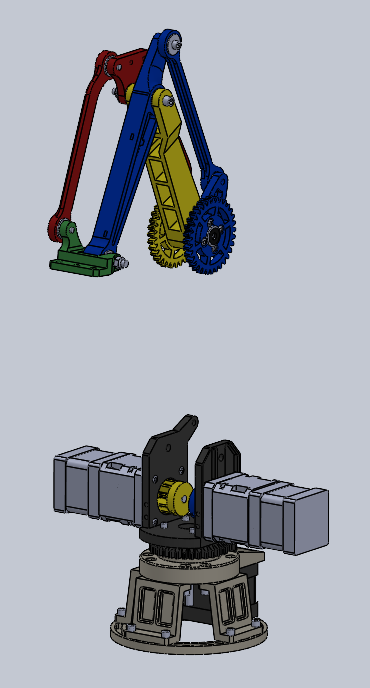
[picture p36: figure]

## 2. Building Instruction

Final assembly

Part name | Count
M5 60mm | 1
M5 너트 (나일론) | 1

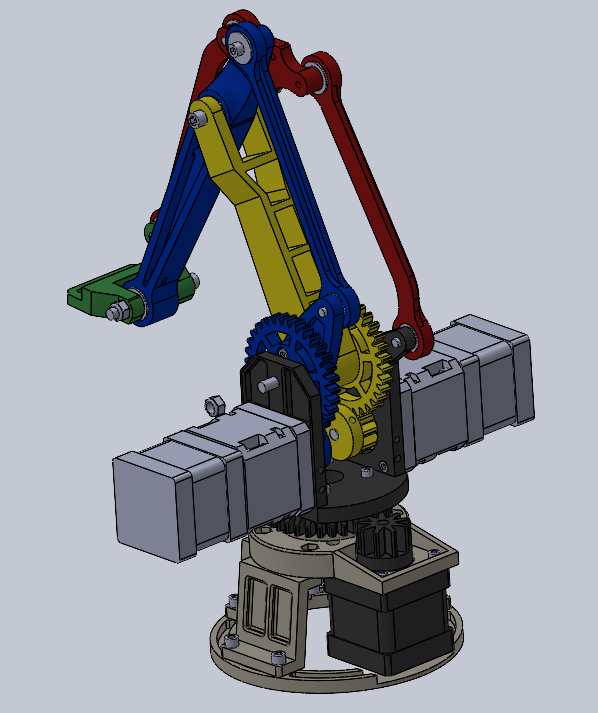
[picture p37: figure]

## 2. Building Instruction

Final assembly

Part name | Count
M4 15mm | 2
M4 와셔 | 4
M4 와셔 (대형) | 2
베어링 624ZZ (M4) | 2

대형 와셔

와셔

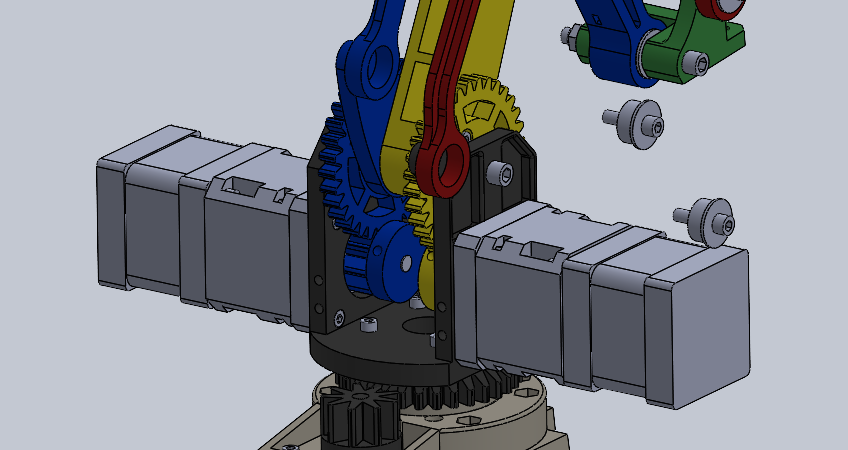
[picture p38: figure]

## 2. Building Instruction

Final assembly

Part name | Count
M3 8mm | 8

Required Parts

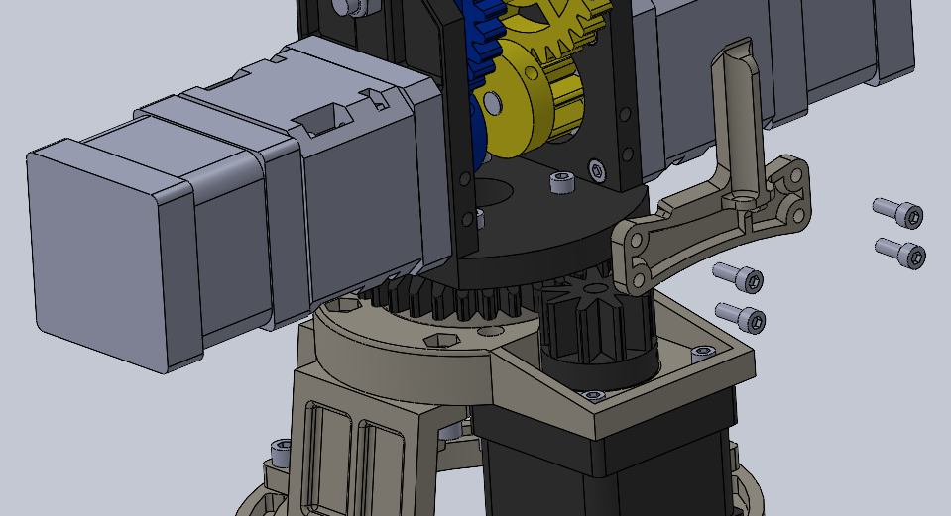
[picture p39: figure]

## 2. Building Instruction

Final assembly

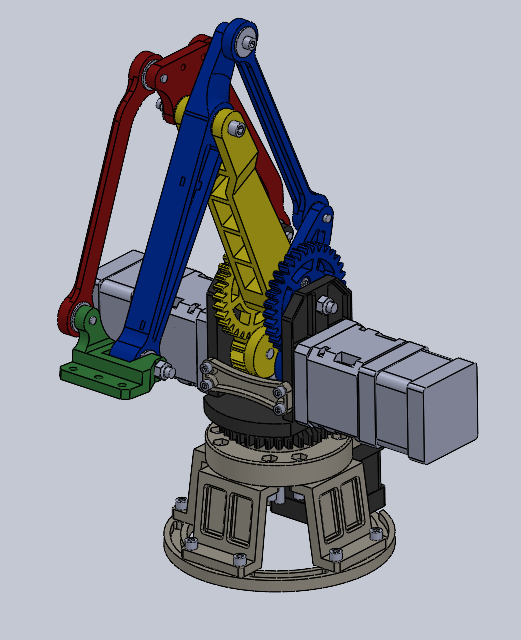
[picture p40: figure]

## 그리퍼 형태

- 볼트 M3 : 15, 10
- 나일론 너트 M3 1

https://www.thingiverse.com/thing:4812073
https://www.thingiverse.com/thing:1454048

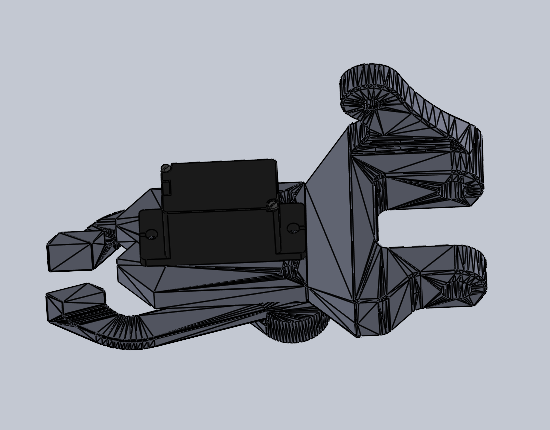
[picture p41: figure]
스케치, 그림이(가) 표시된 사진 AI 생성 콘텐츠는 정확하지 않을 수 있습니다.

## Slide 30

Thanks.

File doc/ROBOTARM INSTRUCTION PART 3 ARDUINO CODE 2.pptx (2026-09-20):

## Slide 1

ROBOT ARM INSTRUCTION
PART.3 – ARDUINO CODE

Prof. Wooyong Kim
Assistant. Dongsik Park
Department of Biomedical & Robotics Engineering,
Incheon National University

Summer, 2026

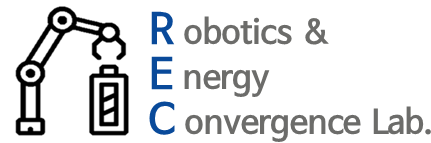
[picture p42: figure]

## Table of Contents

  1. learning objectives – Forward Kinematics
  2. Forward Kinematics needs
  3. Direction of control practice
  4. Stepper motor
  5. Stepper motor action & Angle input action
  6. Gear ratio calculate
  7. Current angle check
  8. Forward Kinematics
  9. Inverse Kinematics
  10. How to design

## learning objectives – Forward Kinematics

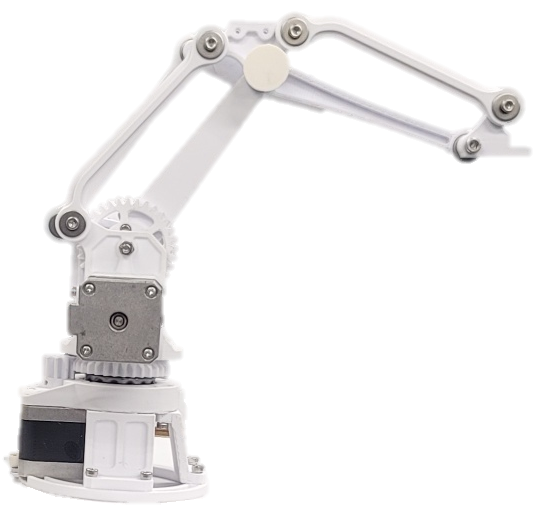
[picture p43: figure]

INPUT: ANGLE OUTPUT: COORDINATE
B_x =L_1 sin(θ_1 )
B_y =L_1 cos(θ_1 )
A_x =B_x +L_3 cos(θ_3 )
A_y =B_y −L_3 sin(θ_3 )
E_x =A_x +wd
E_y =A_y

B_x ,B_y

θ_3

L_3

wd

E_x ,E_y

L_1

A_x ,A_y

θ_1

## Forward Kinematics needs

INPUT: ANGLE OUTPUT: COORDINATE
B_x =L_1 sin(θ_1 )
B_y =L_1 cos(θ_1 )
A_x =B_x +L_3 cos(θ_3 )
A_y =B_y −L_3 sin(θ_3 )
E_x =A_x +wd
E_y =A_y

B_x ,B_y

θ_3

L_3

wd

E_x ,E_y

L_1

A_x ,A_y

θ_1

Trigonometric coordinate

Motor angle control

Current angle check

Gear ratio calculation

## Direction of control practice

1. Manipulator should be operated using manual control code instead of backdrive
2. SDK for additional function queries

SDK

https://www.airspayce.com/mikem/arduino/AccelStepper/classAccelStepper.html

## Stepper motor

VIDEO

https://www.youtube.com/watch?v=09Mpkjcr0bo&t=188s

## Stepper motor action & angle input action

void loop()
{
rotationmovementinsert(3200,0,0)
anglemovementinset(360,0,0);//붐 30도 이동
}
void rotationmovementinsert(long base,long boom,long arm)
{
//0~3200사이 값을 입력 받아 스텝값으로 저장(마이크로 스텝은 16배인 3200)
positions[robot_position_base] = base;
positions[robot_position_arm] = arm;
positions[robot_position_boom] = boom;
steppers.moveTo(positions); //포지션 입력
steppers.runSpeedToPosition(); //각각 동작
}

## Stepper motor action & angle input action

void anglemovementinset(double angle_base, double angle_boom, double angle_arm)
{
double instantbo, instantba, instantar;//지역 변수 선언
//베이스의 경우 감속기어가 없이 평기어만 부착되어있음에 원하는 각도에 따라 요구되는 스텝수 계산 수식
//1.스텝모터 1회전(360도)시 요구되는 스텝 = 200, (1스텝당 1.8도 이동)
//2.마이크로 스텝 설정시, 스텝 2,4,8,16배 증폭가능, 16배 증폭에 따라 스텝모터 1회전시 요구되는 스텝 = 200*16
//3.원하는 각도 입력시 상응하는 스텝수 계산식 = (angle/360)*200*16
instantba = (angle_base*microstep/360);
instantbo = (angle_base*microstep/360);
instantar = (angle_base*microstep/360);
//4.계산된 스텝값 인자로 입력, 이때, 스텝수는 long 형이고 현재는 세밀한 계산을 위해 형변환 입력
rotationmovementinsert((long)instantba, (long)instantbo, (long)instantar);
}

## Gear ratio calculate

- Gear Teeth Count & Form SUN gear : 8 - INPUT PLANET gear : 12 - OUTPUT RING gear : 32 - HOLD
- Formular : 1+r/s=1+(32/8)=5

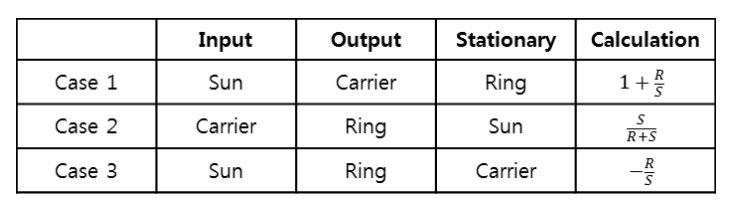
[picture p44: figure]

## Gear ratio calculate

void anglemovementinset(double angle_base, double angle_boom, double angle_arm)
{
double instantbo, instantba, instantar;//지역 변수 선언
//1.스텝모터 1회전(360도)시 요구되는 스텝 = 200, (1스텝당 1.8도 이동)
//2.마이크로 스텝 설정시, 스텝 2,4,8,16배 증폭가능, 스텝모터 1회전시 스텝 = 200*16
//3.평기어 기어비 = 32/9(3.56)임에따라 평기어 1회전시 스텝 = 200*16*3.56
//4.추가적으로 5:1감속기어가 부착, 감속기어 1회전 스텝수 = 200*16*3.56*5
//5.원하는 감속기어 각도 입력시 이에 상응하는 스텝수 계산식 = (angle/360)*200*16*3.56*5
instantba = (angle_base*microstep/360);
instantbo = (planetarygear*angle_boom*smallgearstep*microstep*normgear/360);
instantar = (planetarygear*angle_arm*smallgearstep*microstep*normgear/360);
rotationmovementinsert((long)instantba, (long)instantbo, (long)instantar);
}

## Current angle check

void currentpositionshower()//현재 각도를 출력하는 함수
{
long instantshower;//지역변수
instantshower = base.currentPosition();//프로그램 내부적으로 베이스 모터의 현재 스텝 값을 읽어옴
baseangle_current = (double)instantshower*360/(smallgearstep*microstep*normgear);//기어비 계산후 저장
Serial.print("\nangle current base:");
Serial.println(baseangle_current);//각도 출력
instantshower = boom.currentPosition();
boomangle_current = (double)instantshower*360/(smallgearstep*microstep*planetarygear*normgear);//감속기어 부착
Serial.print("angle current boom:");
Serial.println(boomangle_current);
instantshower = arm.currentPosition();
armangle_current = (double)instantshower*360/(smallgearstep*microstep*planetarygear*normgear);
Serial.print("angle current arm:");
Serial.println(armangle_current);
}

## Forward Kinematics

INPUT: ANGLE OUTPUT: COORDINATE
B_x =L_1 sin(θ_1 )
B_y =L_1 cos(θ_1 )
A_x =B_x +L_3 cos(θ_3 )
A_y =B_y −L_3 sin(θ_3 )
E_x =A_x +wd
E_y =A_y

B_x ,B_y

θ_3

L_3

wd

E_x ,E_y

L_1

A_x ,A_y

θ_1

## Forward Kinematics

void Foward_Kinematics_Action(double input_base,double input_boom,double input_arm)
{
Foward_Kinematics_Calculator(input_base,input_boom,input_arm);//입력 각도에 따른 좌표 계산
anglemovementinset(input_base,input_boom,input_arm);//각도 입력 및 이동
currentpositionshower();//현재 좌표 출력
}
void Foward_Kinematics_Calculator(double angle_base, double angle_boom, double angle_arm)
{
//double boom_L1 = 12.0;//boom의 길이
//double arm_L3 = 12.0;//arm의 길이
//double endeffectoroffset_wd = 3.0;//arm의 끝과 엔드이펙터 사이의 거리
angle_arm = radians(angle_arm);//입력 각도 도 -> 라디안 변환
angle_boom = radians(angle_boom);//입력 각도 도 -> 라디안 변환
double x_boom = boom_L1*sin(angle_boom);//붐의 끝부분 평면 좌표 x축 = sin(붐 각도)*붐 길이
double y_boom = boom_L1*cos(angle_boom)+y_offset;//붐의 끝부분 평면 좌표 y축 = cos(붐 각도)*붐 길이 + 본체 높이 오프셋 길이
double x_arm = x_boom+(arm_L3*cos(angle_arm));//암의 끝부분 평면 좌표 x축 = cos(암각도)*암 길이 + 붐 x좌표
double y_arm = y_boom-(arm_L3*sin(angle_arm));//암의 끝부분 평면 좌표 y축 = sin(암각도)*암 길이*-1 + 붐 y좌표()세타 3가 기준이라 반대로 이동
double x_end = x_arm+endeffectoroffset_wd;//최종 좌표 + 엔드이펙터 오프셋 거리
double y_end = y_arm;//최종 좌표
}

## Inverse Kinematics

A

c

b

a

1. second hyperbolic law of cosines
a^2 =b^2 +c^2 −2bccos(A)
(−a^2 +b^2 +c^2)/(2bc)=cos(A)
acos((−a^2 +b^2 +c^2)/(2bc))=A° … ①

2. Pythagoras' theorem
a^2 =b^2 +c^2 … ②

c

a

b

## Inverse Kinematics

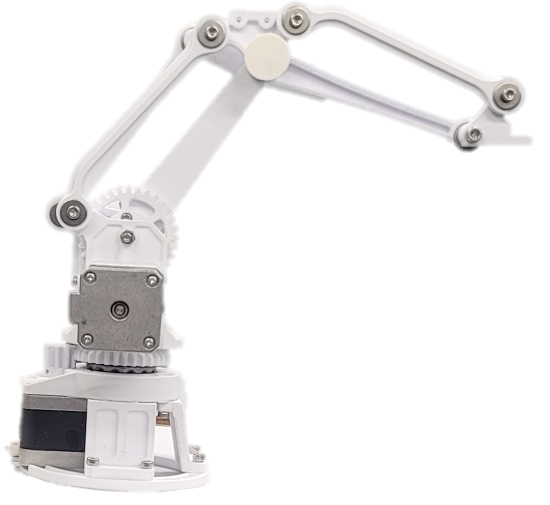
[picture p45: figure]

INPUT:COORDINATE OUTPUT:ANGLE
E_x =A_x +wd, E_y =A_y
D=√(A_x^2 +E_y^2) … ②
acos((L_1^2 +L_3^2 −D^2)/(2L_1 L_3))=θ_21 …①
acos((L_1^2 +D^2 −L_3^2)/(2L_1 D))=θ_α …①
acos((D^2 +(E_x −wd)^2 −E_y^2)/(2D(E_x −wd)))=θ_β …①
θ_γ ={, θ_α +θ_β , E_y ≥0, &θ_α −θ_β , E_y <0
θ_1 =90−θ_γ
θ_3 =180 −(θ_21 +θ_γ )

θ_γ

B_x ,B_y

θ_3

θ_21

L_3

wd

E_x ,E_y

L_1

A_x ,A_y

θ_3

θ_1

θ_α

θ_γ

D

θ_β

## Inverse Kinematics

INPUT:COORDINATE OUTPUT:ANGLE
E_x =A_x +wd, E_y =A_y
D=√(A_x^2 +E_y^2) … ②
acos((L_1^2 +L_3^2 −D^2)/(2L_1 L_3))=θ_21 …①
acos((L_1^2 +D^2 −L_3^2)/(2L_1 D))=θ_α …①
acos((D^2 +(E_x −wd)^2 −E_y^2)/(2D(E_x −wd)))=θ_β …①
θ_γ ={, θ_α +θ_β , E_y ≥0, &θ_α −θ_β , E_y <0
θ_1 =90−θ_γ
θ_3 =180 −(θ_21 +θ_γ )

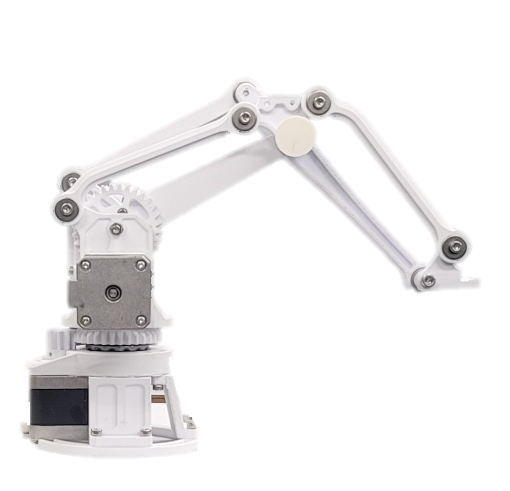
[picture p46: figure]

θ_γ

θ_21

θ_3

B_x ,B_y

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
A_x ,A_y

E_x ,E_y

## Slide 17

Inverse Kinematics

void Inverse_Kinematics_Calculator(double P_x, double P_y)
{
// double boomangle_th1, armangle_th2, th21, D, alpha, psi;
// y_offset, endeffectoroffset_wd, boom_L1, arm_L3
// P_x, P_y
double boomangle_th1, armangle_th2, th21, D, alpha, psi;
//1. 계산의 편의를 위해 엔드이펙터 관절부로 오프셋 차감 2 줄
P_y -= y_offset;//오프셋 제거
P_x -= endeffectoroffset_wd;//오프셋 제거
//2. 피타고라스 정리를 이용하여 D 계산 1 줄
D = sqrt(pow(P_x, 2) + pow(P_y, 2));//엔드이펙터 관절의 3차원 공간 위치
//3. 제2 코사인 법칙을 통해 붐과 암 사이 각(th21) 구하기 1 줄
th21 = acos((pow(boom_L1, 2) + pow(arm_L3, 2) - pow(D, 2)) / (2 * boom_L1 * arm_L3));
//4. 제2 코사인 법칙을 통해 D와 붐 사이 각(alpha) 구하기 1 줄
alpha = acos((pow(boom_L1, 2) + pow(D, 2) - pow(arm_L3, 2)) / (2 * boom_L1 * D));
//5. 제2 코사인 법칙을 통해 지면과 붐 사이 각(beta = psi) 구하기 1 줄
psi = acos((pow(D, 2) + pow(P_x, 2) - pow(P_y, 2)) / (2 * D * P_x));
}

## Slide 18

Inverse Kinematics

void Inverse_Kinematics_Calculator(double P_x, double P_y)
{
//6. 계산된 3개의 라디안 도 변환 (deg = rad*180/PI) 3 줄
alpha = degrees(alpha);
psi = degrees(psi);
th21 = degrees(th21);//붐 암 사이 각
//7. 붐 중앙축 y좌표 기준 엔드이펙터의 y좌표가 이상(alpha + psi)인지 이하(alpha - psi)별 수식 작성 = 붐 각도(boomangle_th1) 계산 2
if (P_y >= 0) boomangle_th1 = alpha + psi;//만약 엔드이펙터의 높이가 boom,arm 모터의 중심보다 위에 있을경우
else boomangle_th1 = alpha - psi;//만약 엔드이펙터의 높이가 boom,arm 모터의 중심보다 아래에 있을경우
//8. 사잇각(th21) + 붐 각도(boomangle_th1) = 암 각도(armangle_th2) 계산 1 줄
armangle_th2 = th21 + boomangle_th1; //암 모터 각도
//9. 모터에 맞는 기준축 간의 각도 값 변환((-1*boomangle_th1)+90, (-1*armangle_th2)+180 = out_boomangle, out_armangle) 2 줄
out_boomangle = (-1*boomangle_th1)+90;//오프셋 제외 최종 각도 붐
out_armangle = (-1*armangle_th2)+180;//오프셋 제외 최종 각도 암
}

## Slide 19

How to design

In order to put the desired action, created a separate function to put the code in performance_(1~6).
Practice
1. Write the desired action to the function (ex. performance_1) and upload it.
2. Modify the initial posture with the manual control button
3. Initialize with Arduino reset button
4. Enforce the desired action
5. Emergency stop in case of an abnormality in operation

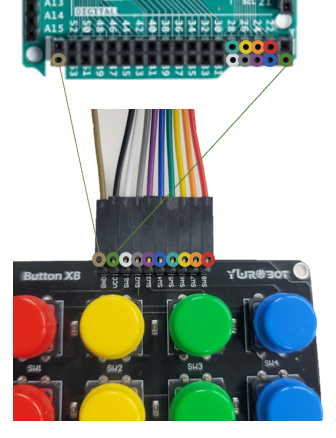
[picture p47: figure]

Bottom Blue button: button Angular manual control
Top blue button: Serial communication InverseKinematics manual control
(‘w,a,s,d' input in the serial window and moved, ‘q,e,f,g’ just setted.)
Bottom green button: performance_1
Top green button: performance_2
Bottom Yellow button: perfomance_3
Top Yellow button: perfomance_4
Bottom red button: perfomance_5
Top red button: perfomance_6

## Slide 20

Thanks.

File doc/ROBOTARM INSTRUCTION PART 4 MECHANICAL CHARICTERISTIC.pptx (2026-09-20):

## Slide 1

ROBOT ARM INSTRUCTION
PART.4 – MECHANICAL CHARACTERISTICS

Prof. Wooyong Kim
Assistant. Dongsik Park
Department of Biomedical & Robotics Engineering,
Incheon National University

Summer, 2026


## Table of Contents

  1. Planetary Gear
  2. Forward Kinematics
  3. Inverse Kinematics

## 1. Planetary Gear

Specific & Caculation

- Gear Teeth Count & Form SUN gear : 8 - INPUT PLANET gear : 12 - OUTPUT RING gear : 32 - HOLD
- Formular : 1+r/s=1+(32/8)=5


## 2. Forward Kinematics


INPUT: ANGLE OUTPUT: COORDINATE
B_x =L_1 sin(θ_1 )
B_y =L_1 cos(θ_1 )
A_x =B_x +L_3 cos(θ_3 )
A_y =B_y −L_3 sin(θ_3 )
E_x =A_x +wd
E_y =A_y

B_x ,B_y

θ_3

L_3

wd

E_x ,E_y

L_1

A_x ,A_y

θ_1

We convert angles to align with different reference points: in math, angles are counterclockwise from the x-axis, but in this robotic arm, angles like theta 1 and theta 3 are measured clockwise from specific lines.

## 3. Inverse Kinematics

A

c

b

a

1. second hyperbolic law of cosines
a^2 =b^2 +c^2 −2bccos(A)
(−a^2 +b^2 +c^2)/(2bc)=cos(A)
acos((−a^2 +b^2 +c^2)/(2bc))=A° … ①

2. Pythagoras' theorem
a^2 =b^2 +c^2 … ②

c

a

b

## 3. Inverse Kinematics


INPUT:COORDINATE OUTPUT:ANGLE
E_x =A_x +wd, E_y =A_y
D=√(A_x^2 +E_y^2) … ②
acos((L_1^2 +L_3^2 −D^2)/(2L_1 L_3))=θ_21 …①
acos((L_1^2 +D^2 −L_3^2)/(2L_1 D))=θ_α …①
acos((D^2 +(E_x −wd)^2 −E_y^2)/(2D(E_x −wd)))=θ_β …①
θ_γ ={, θ_α +θ_β , E_y ≥0, &θ_α −θ_β , E_y <0
θ_1 =90−θ_γ
θ_3 =180 −(θ_21 +θ_γ )

θ_γ

B_x ,B_y

θ_3

θ_21

L_3

wd

E_x ,E_y

L_1

A_x ,A_y

θ_3

θ_1

θ_α

θ_γ

D

θ_β

## 3. Inverse Kinematics

INPUT:COORDINATE OUTPUT:ANGLE
E_x =A_x +wd, E_y =A_y
D=√(A_x^2 +E_y^2) … ②
acos((L_1^2 +L_3^2 −D^2)/(2L_1 L_3))=θ_21 …①
acos((L_1^2 +D^2 −L_3^2)/(2L_1 D))=θ_α …①
acos((D^2 +(E_x −wd)^2 −E_y^2)/(2D(E_x −wd)))=θ_β …①
θ_γ ={, θ_α +θ_β , E_y ≥0, &θ_α −θ_β , E_y <0
θ_1 =90−θ_γ
θ_3 =180 −(θ_21 +θ_γ )


θ_γ

θ_21

θ_3

B_x ,B_y

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
A_x ,A_y

E_x ,E_y

## 4. Backlash caculate

Ey_x ,Ey_y =backlash minimum angle position
Eb_x ,Eb_x =backlash maximum angle position
backlash maximum angle −backlash minimum angle= θ_b =θ_1 +θ_2

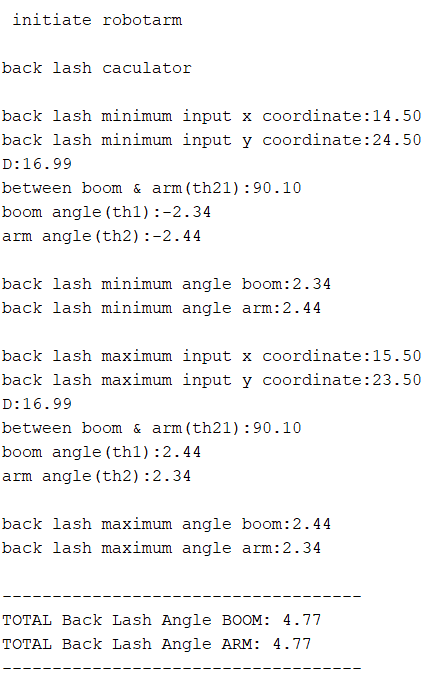
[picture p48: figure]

Eb_x ,Eb_y

θ_2

θ_1

D_b

D_y

Ey_x ,Ey_y

θ_b

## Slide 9

Thanks.

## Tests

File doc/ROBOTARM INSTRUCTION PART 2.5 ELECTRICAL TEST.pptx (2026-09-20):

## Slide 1

ROBOT ARM INSTRUCTION
PART.2 - ELECTRICAL

Prof. Wooyong Kim
Assistant. Dongsik Park
Department of Biomedical & Robotics Engineering,
Incheon National University

Summer, 2026


## Table of Contents

  1. List Of Part
  2. Circuit Diagram
  3. Wiring Diagram
  4. Detail connection
  5. ETC

## 1. List Of Part

3D Print

Part name | Number
바디_접지링 | 1
바디_그라운드 | 1
바디_메인바디 | 1
바디_지지대 | 3
바디_프론트가드 | 1
바디_비하인드가드 | 1
바디_엔드이펙터 | 1
바디_암 | 1
바디_붐 | 1
링크_엔드이펙터컨트롤 | 1
링크_암컨트롤 | 1
링크_암 | 1
링크_붐 | 2
기어_모터_너트(2개 여분) | 5
기어_붐암 | 2
기어_바디 | 1
가이드 | 2
선기어 | 2
케이지 | 2
페이스 | 2
플래닛기어 | 6

Mechanical Material

(Need) hex key(육각렌치) – 1.5, 3, 4, 5 mm

Part name | Number
M3 8 무두 | 10
M3 8 | 28
M3 12 | 4
M3 15 | 6
M3 20 | 8
M4 10 | 6
M4 15 | 12
M5 45 | 3
M5 60 | 1
M5 30 육각 | 2
M3 너트 | 22
M4 너트 | 6
M3 나일론 너트 | 6
M5 나일론 너트 | 4
M4 와셔 | 12
M5 와셔 | 24
M4 와셔 대형 | 8
M5 와셔 대형 | 20
베어링 51105(25-42-11) | 1
베어링 695ZZ(5-13-4) | 18
베어링 624ZZ(4-13-5) | 6
베어링 683ZZ | 12
베어링 F695ZZ | 1

Circuit Material

(Need) Phillips screwdriver (십자드라이버)

Part name | Number
스텝모터 | 3
아두이노 메가 | 1
A4988 드라이버 | 3
드라이브 보드 | 1
점퍼캡 | 9
파워서플라이 | 1
배럴잭 | 1
핀헤더 | 2
푸시락 버튼 | 1
8버튼 | 1
전선 | 13

## 2. Circuit Diagram

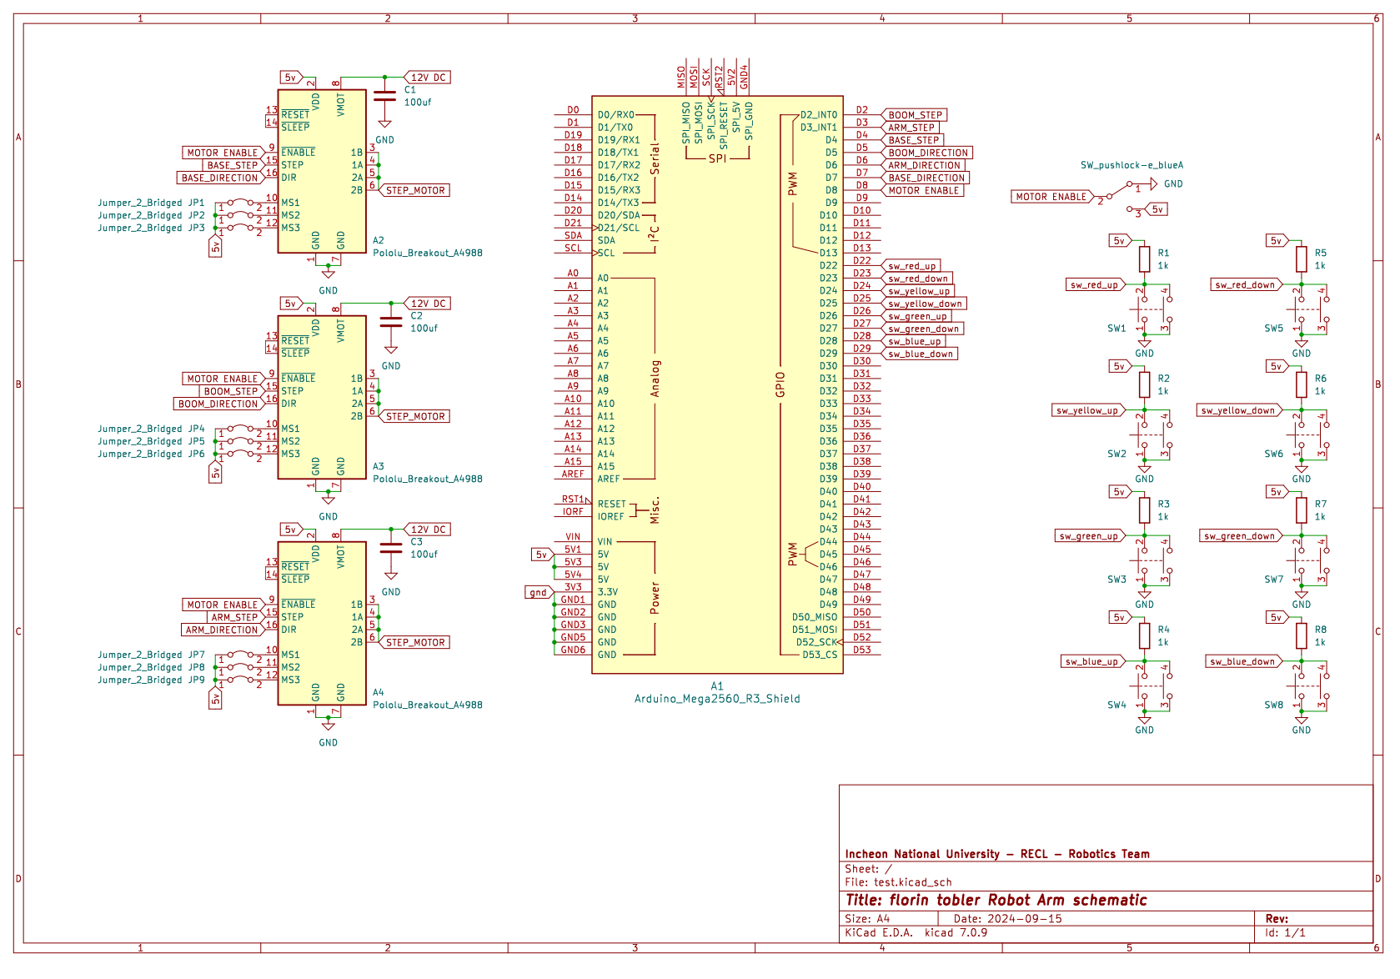
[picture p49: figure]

## 3. Composition Diagram

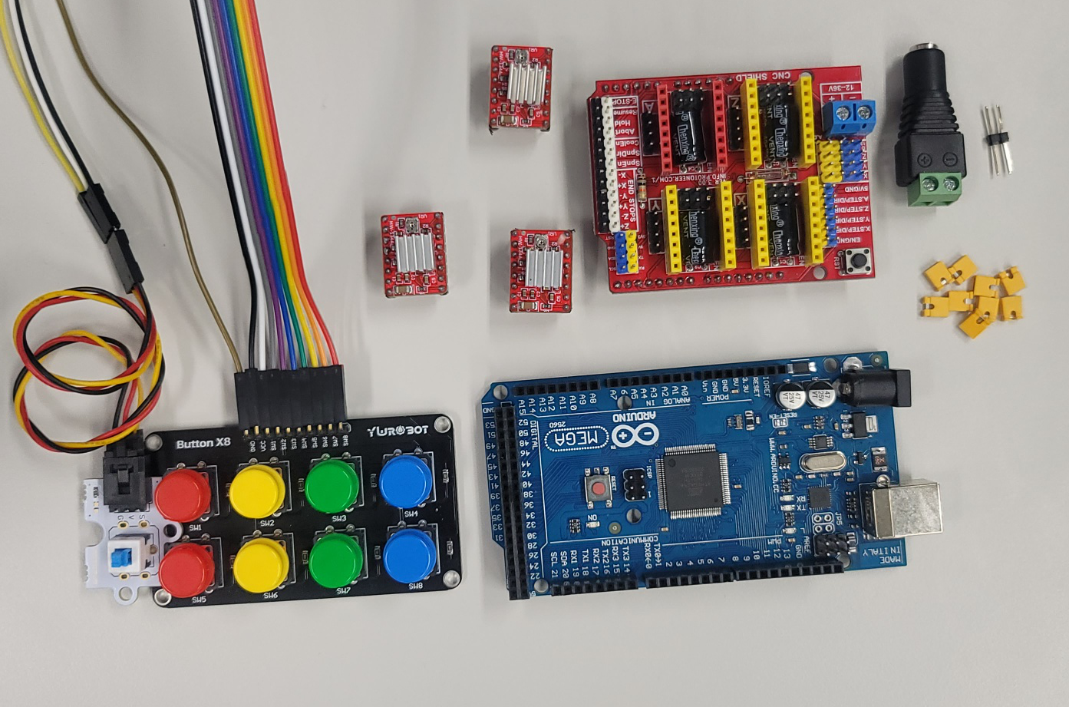
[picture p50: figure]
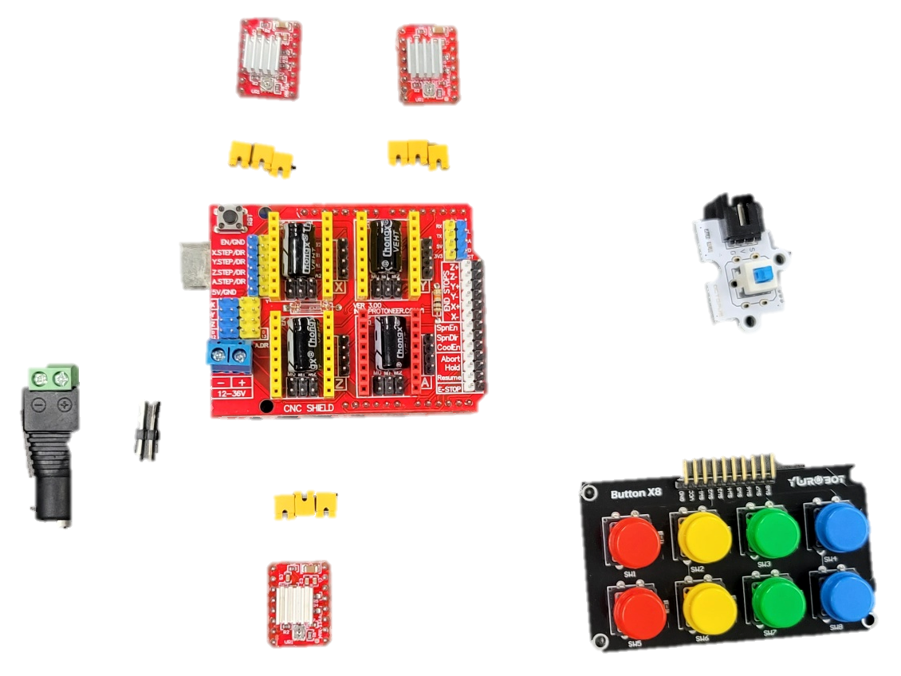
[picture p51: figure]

스텝모터

아두이노 메가 & 드라이브 보드(CNC 쉴드)

푸시락 버튼

핀헤더

DC 배럴잭(암)

점퍼캡

A4988 드라이버

8버튼

## 4. Detail connection

Micro step jumper cap connection & Torque setting

CW / CCW turn = Torque control

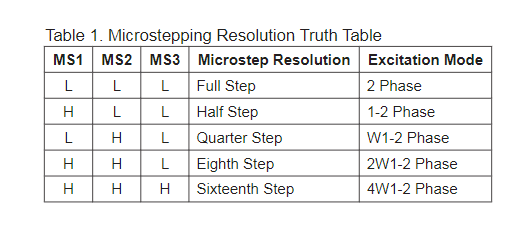
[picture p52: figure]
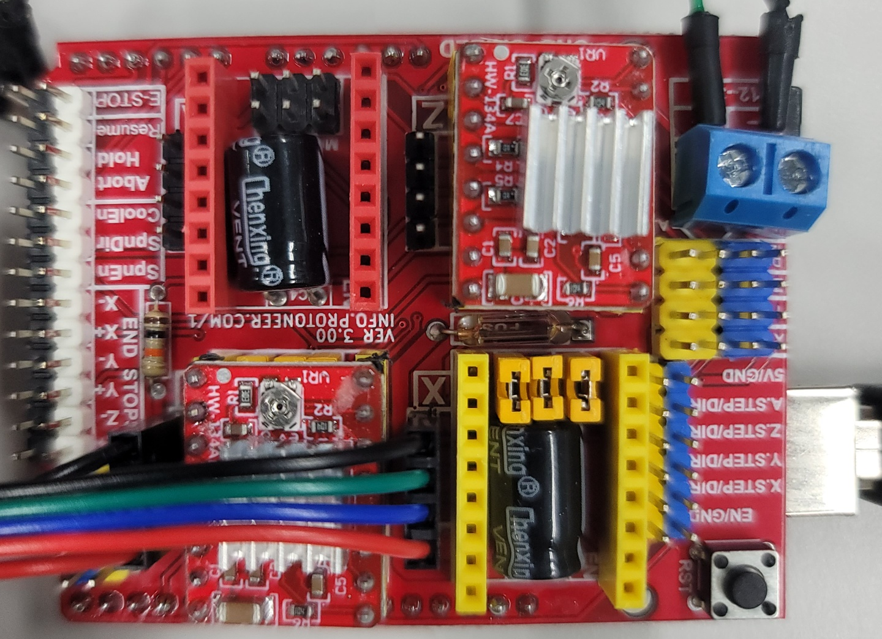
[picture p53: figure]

## 4. Detail connection

Emergency & Button switch

GND VCC SW

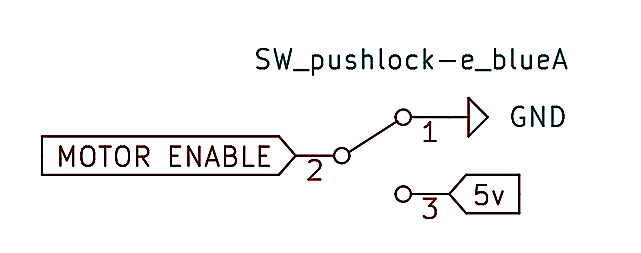
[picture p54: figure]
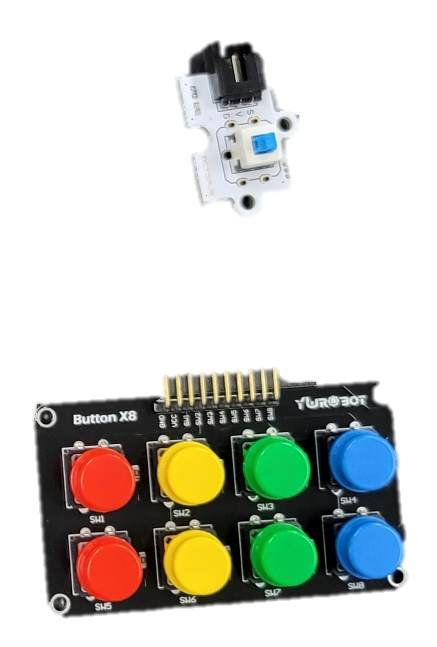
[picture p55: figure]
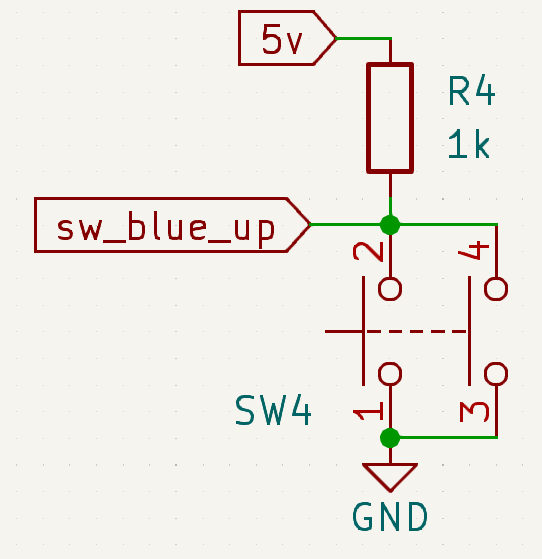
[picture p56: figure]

## 4. Detail connection

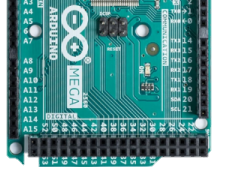
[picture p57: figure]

8 button connection

- Purpose: Button signal
- Wire each color by color

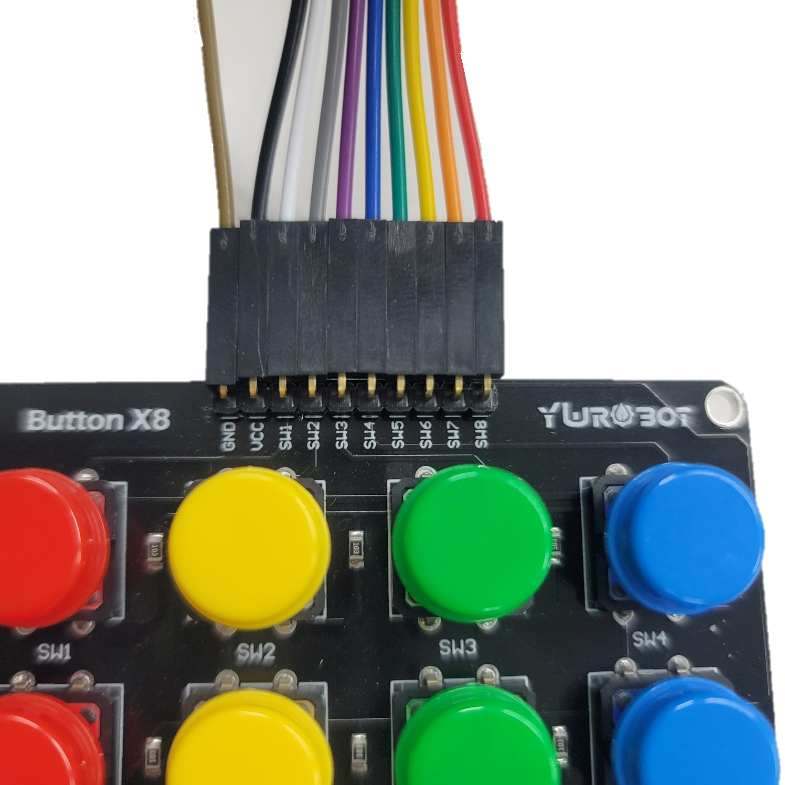
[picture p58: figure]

## 5. ETC

Original CNC shield schematic


## 5. ETC


Original CNC shield function pin

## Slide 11

Thanks.

## 5. Test code

Button Input

- 버튼의 입력에 따라 다양한 문자열 출력
- 시리얼 문자열 출력
- 버튼에 연결된 상태 시리얼 출력
- 버튼 입력에 따라 다른 문자열 출력

## 5. Test code

Q. Step 모터를 입력한 각도별 동작하는 코드를 작성하시오

- 30분간 수단과 방법을 가리지 않고
- 팀원부터 조교까지 논의 OK
- PART2 전장 결선 참고

## 5. Test code

Q. 버튼별 지정된 Step 모터 각도 동작 코드 작성

- 1번 버튼을 누르면 30도
- 2번 버튼을 누르면 60도
- 3번 버튼을 누르면 90도
- 4번 버튼을 누르면 180도
- 5,6,7,8은 각각 반대로회전

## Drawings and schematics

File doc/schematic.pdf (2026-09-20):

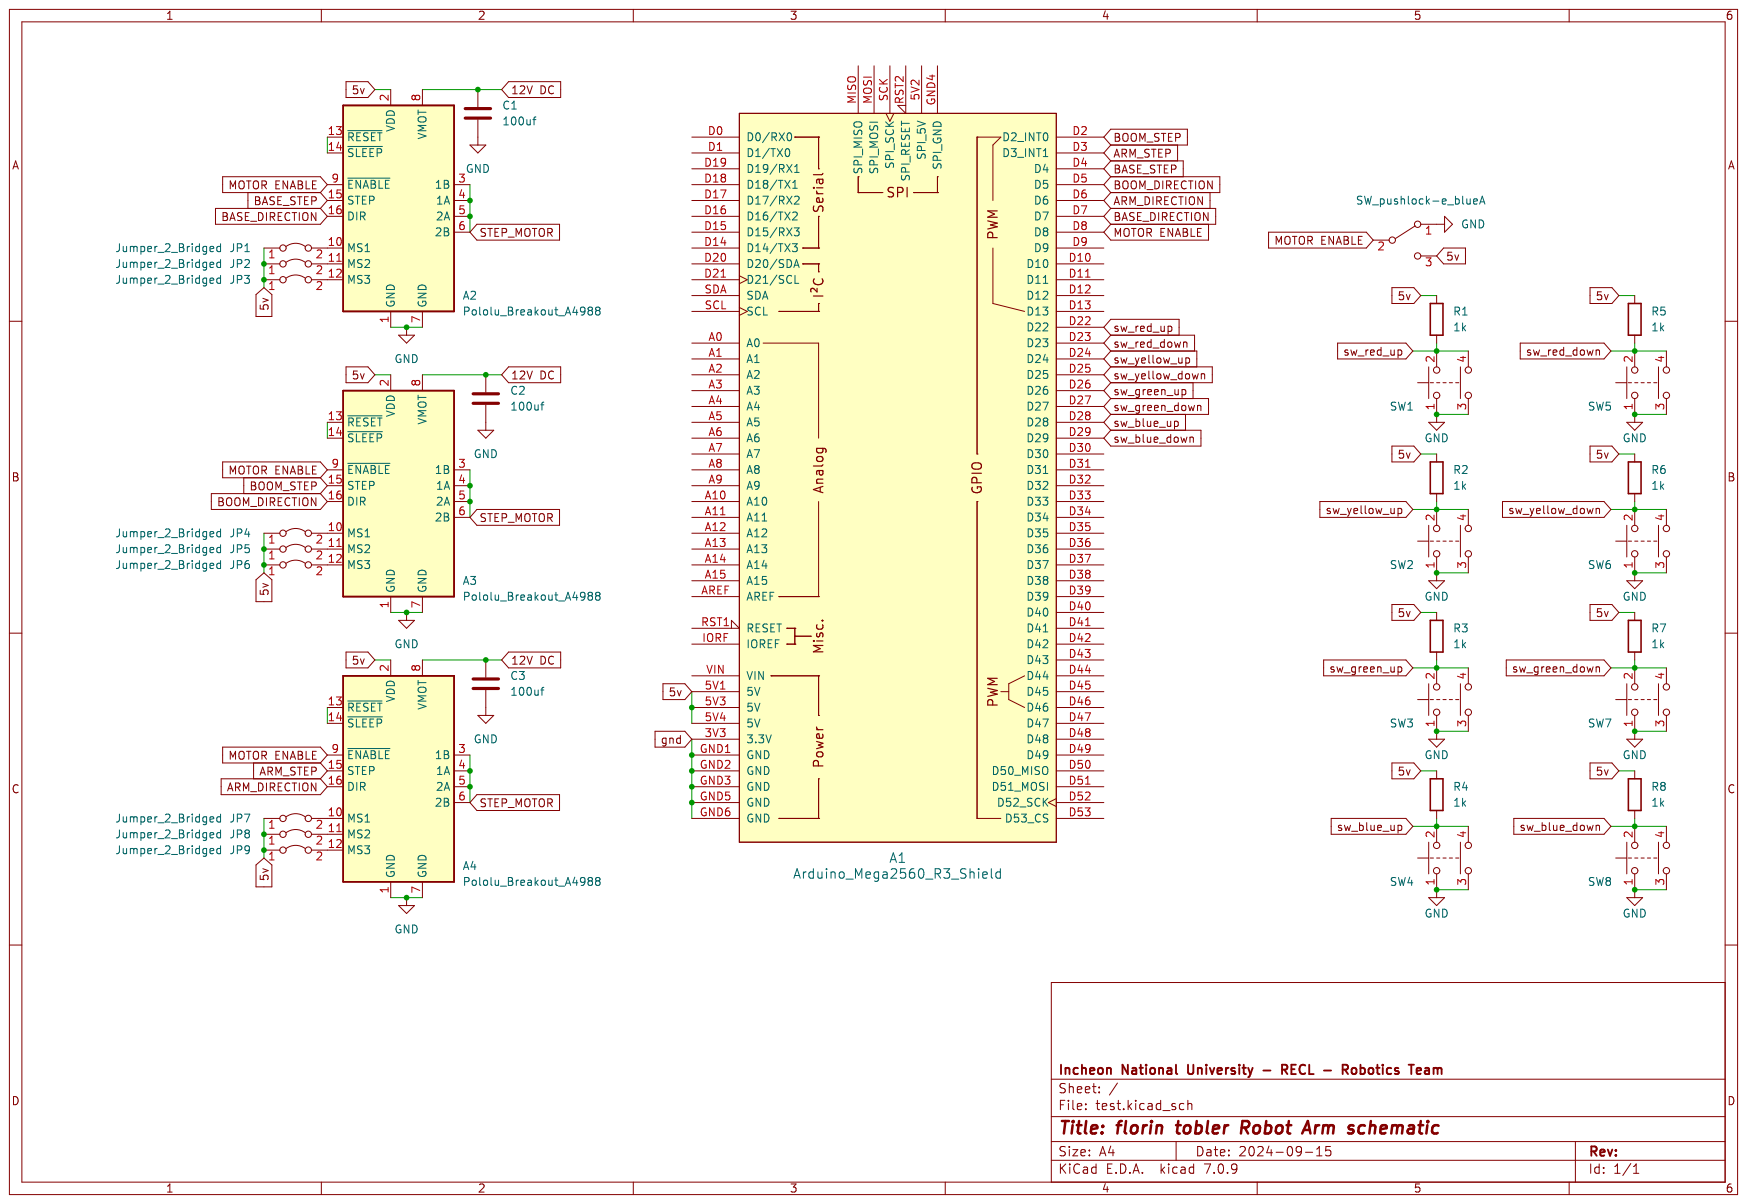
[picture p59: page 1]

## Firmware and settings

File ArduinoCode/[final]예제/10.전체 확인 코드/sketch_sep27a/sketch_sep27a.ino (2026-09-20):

/*
 * Incheon National University
 * Project:    PARALLEL ROBOT ARM CONTROL
 * Laboratory: Robotics & Energy Convergence Lab
 * Date:       2024 FALL
 * Professor:  Wooyong Kim
 * Assistant:  Dongsik Park
 * 
 * mEmO
 * cnc구조 관련 링크
 * http://john-home.iptime.org:8085/xe/index.php?mid=board_jalN13&document_srl=1060
 * 아두이노 cnc쉴드 써서 제작 xyz라고 쓰여진데 있어서 하나 다른데(붉은 부분)만 안넣으면됨
 * z가 베이스
 * y가 링크1 암
 * x가 링크2 붐
 * a4988 드라이버 사용
 * 핀맵은 하단부에 적어둠
 * accelstepper, multistepper 라이브러리 같이쓰기
 * d8 enable 기능 gnd 동작이라서 스위치 연결하면 전원 항시 연결에 동작 활성화 비활성화 할수있음
 * a0123에 조이스틱 연결
 * d22~29에 스위치 연결
 * 마이크로 스텝 활성화시 점퍼캡 사용할 것
 * 
 * 마이크로 스텝
 * 분주비 16:1
 * 감속기어 비율 5:1
 * 작은 기어 회전에 걸리는 풀 스텝 수 200
 * 큰기어와 작은 기어간 기어비 9:32 - 3.555 * 200 = 711
 * NEMA 17급 / 바이폴라 방식 / 마이크로스텝 구동
 * 파워 서플라이 12V 5A
 * StandAlone시 레귤레이터 부착 요구
 */

#include <AccelStepper.h>
#include <MultiStepper.h>

#define ON  1
#define OFF 0

#define xbuf    22
#define xbub    23
#define ybuf    24
#define ybub    25
#define zbuf    26
#define zbub    27
#define gbuf    28
#define gbub    29

//boom
#define DIR0    5
#define STEP0   2
//arm
#define DIR01   6
#define STEP01  3
//base
#define DIR02   7
#define STEP02  4

#define robot_position_base 0
#define robot_position_boom 1
#define robot_position_arm  2

#define smallgearstep       200     //one circle for step
#define microstep           16      //microstep
#define normgear            3.56    //32/9 = 3.5556
#define planetarygear       5       //5:1

#define description         OFF     //description 0 off 1 on

AccelStepper base = AccelStepper(1, STEP02, DIR02);//BASE
AccelStepper boom = AccelStepper(1, STEP0, DIR0);//BOOM
AccelStepper arm = AccelStepper(1,STEP01, DIR01);//ARM

MultiStepper steppers;

long positions[3];//위치 전역 변수 배열, 여기에 저장된 값이 모터별 위치 지정값이 됨
int modenum = 0,minval = 300, maxval = 700, midval = 500;//조이스틱 ADC 값 각각 최소 최대 중앙 값, 모드 선택
float speedmotor = 1200.0;//제한 최대 속도
double armangle_current, boomangle_current, baseangle_current;//현재 각도 전역 변수
double out_boomangle, out_armangle;//역기구학 출력 각도 전역 변수
double manual_x=15 , manual_y = 24;//수동좌표 시작 상태 변수, [cm]
double posx = 12.0, posy = 12.0, posz=0.0, y_offset=12;//xy 평면 좌표, z 회전 각도, 로봇 붐 관절 중앙 지면 사이 길이
double boom_L1 = 12.0;//boom의 길이
double arm_L3 = 12.0;//arm의 길이
double endeffectoroffset_wd = 3.0;//arm의 끝과 엔드이펙터 사이의 거리

void perfomance_1();
void perfomance_2();
void perfomance_3();
void perfomance_4();
void manualcontroller3();//매뉴얼 버튼 컨트롤러 모드
void rotationmovementinsert(long base,long boom,long arm);//스텝 회전수 입력 동작
void anglemovementinset(double angle_base, double angle_boom, double angle_arm);//각도 입력 동작
void currentpositionshower();//현재 위치 각도 산출 함수
void Foward_Kinematics_Calculator(double angle_base, double angle_boom, double angle_arm);//정기구학 계산 입력:각도, 출력:좌표
void Foward_Kinematics_Action(double input_base,double input_boom,double input_arm); //정기구학 출력
void Inverse_Kinematics_Calculator(double P_x, double P_y);//역기구학 위치 계산 입력:좌표, 출력:각도
void Inverse_Kinematics_Action(double R_z,double Pos_x, double Pos_y);//역기구학 출력
void Back_Lash_caculator(double input_x_min,double input_y_min,double input_x_max,double input_y_max);
void perfomance_check();//기능 확인

void setup()
{    
  //포트 세팅
  pinMode(DIR0,OUTPUT);
  pinMode(STEP0,OUTPUT);
  pinMode(DIR01,OUTPUT);
  pinMode(STEP01,OUTPUT);
  pinMode(DIR02,OUTPUT);
  pinMode(STEP02,OUTPUT);

  //시리얼 모듈 활성화
  Serial.begin(9600);

  pinMode(xbuf,INPUT);
  pinMode(xbub,INPUT);
  pinMode(ybuf,INPUT);
  pinMode(ybub,INPUT);
  pinMode(zbuf,INPUT);
  pinMode(zbub,INPUT);
  pinMode(gbuf,INPUT);
  pinMode(gbub,INPUT);

  Serial.print("\n initiate robotarm\n\n");

  //제한 최대 속도
  speedmotor = 1200.0;
  base.setMaxSpeed(speedmotor);
  if(planetarygear==5) speedmotor = 8000.0;
  boom.setMaxSpeed(speedmotor);
  arm.setMaxSpeed(speedmotor);

  //내부 초기 포지션 변수 오픈 루프 제어
  base.setCurrentPosition(0);
  boom.setCurrentPosition(0);
  arm.setCurrentPosition(0);

  //객체 선언 - 이거 순서 바뀌면 절대 안됨
  steppers.addStepper(base);
  steppers.addStepper(boom);
  steppers.addStepper(arm);

  delay(2000);
}

void loop()
{
//  perfomance_check();
  Serial.println();
  Serial.print("initiate robotArm manual mode \n press reset to exit manual mode and reset robotArm");
  Serial.println();
  Serial.print("button controller enable:");
  for(;;) manualcontroller3();
}

void perfomance_1()//픽앤 플레이스
{
  Inverse_Kinematics_Action(90,15,0);
  
  Inverse_Kinematics_Action(90,15,24);

  Inverse_Kinematics_Action(-90,15,24);

  Inverse_Kinematics_Action(-90,15,0);

  Inverse_Kinematics_Action(0,15,24);

  delay(5000);
}

void perfomance_2()//한붓 그리기
{
  int j = 1;

/*
15,10 20,15
20,15 15,20
15,20 10,15
10,15 15,10
*/

  for(double i=24;i>=20;i--) Inverse_Kinematics_Action(0,15,i);
  delay(100*j);

  for(double i=0;i<=5;i++) Inverse_Kinematics_Action(0,15-i,20-i);
  delay(100*j);

  for(double i=0;i<=5;i++) Inverse_Kinematics_Action(0,10+i,15-i);
  delay(100*j);
  
  for(double i=0;i<=5;i++) Inverse_Kinematics_Action(0,15+i,10+i);
  delay(100*j);

  for(double i=0;i<=5;i++) Inverse_Kinematics_Action(0,20-i,15+i);
  delay(100*j);

/*
15,20 20,20
20,20 20,10
20,10 10,10
10,10 10,20
10,20 15,20
*/

  for(int i=15;i<=20;i++) Inverse_Kinematics_Action(0,(double)i,20);
  delay(100*j);

  for(int i=20;i>=10;i--) Inverse_Kinematics_Action(0,20,(double)i);
  delay(100*j);

  for(int i=20;i>=10;i--) Inverse_Kinematics_Action(0,(double)i,10);
  delay(100*j);

  for(int i=10;i<=20;i++) Inverse_Kinematics_Action(0,10,(double)i);
  delay(100*j);

  for(int i=10;i>=15;i--) Inverse_Kinematics_Action(0,(double)i,20);
  delay(100*j);

  for(int i=10;i<=15;i++) Inverse_Kinematics_Action(0,(double)i,20);
  delay(100*j);

  Inverse_Kinematics_Action(0,15,24);

  delay(5000);
}

void perfomance_3()
{
  //make u r move !
}

void perfomance_4()
{
  //make u r move !
}

void perfomance_check()
{
  int counter = 0;
  Serial.print("\n initiate robotArm function checking mode, push button\n");  
  for(;;)
  {
    for(;;)
    {
      if(digitalRead(xbuf)!=1) modenum = 1;
      if(digitalRead(xbub)!=1) modenum = 2;
      if(digitalRead(ybuf)!=1) modenum = 3;
      if(digitalRead(ybub)!=1) modenum = 4;
      if(digitalRead(zbuf)!=1) modenum = 5;
      if(digitalRead(zbub)!=1) modenum = 6;
      if(digitalRead(gbuf)!=1) modenum = 7;
      if(digitalRead(gbub)!=1) modenum = 8;
      if(modenum != 0) break;
    }
    Serial.println(modenum);
    modenum = 0;
    delay(500);
    counter++;
    if(counter == 10) break;
  }

  Serial.print("\n done");
  delay(500);
  Serial.print("\n motor test");

  for(int i =0;i<20;i++)
  {
    rotationmovementinsert(i*50,i*50,i*50);
    delay(10);
  }
  for(int i = 20;i>0;i--)
  {
    rotationmovementinsert(i*50,i*50,i*50);
    delay(10);
  }
  Serial.print("\n done all work\n\n");
}

void Back_Lash_caculator(double input_x_min,double input_y_min,double input_x_max,double input_y_max)
{
  double instbacklash_min_b,instbacklash_min_a,instbacklash_max_b,instbacklash_max_a;

  Serial.print("back lash caculator\n");
  Serial.println();

  Serial.print("back lash minimum input x coordinate:");
  Serial.println(input_x_min);
  Serial.print("back lash minimum input y coordinate:");
  Serial.println(input_y_min);

  //  Inverse_Kinematics_Calculator(15.5,23.5);
  Inverse_Kinematics_Calculator(input_x_min,input_y_min);
  instbacklash_min_b = abs(out_boomangle);
  instbacklash_min_a = abs(out_armangle);
  Serial.print("back lash minimum angle boom:");
  Serial.println(instbacklash_min_b);
  Serial.print("back lash minimum angle arm:");
  Serial.println(instbacklash_min_a);

  Serial.println();

  Serial.print("back lash maximum input x coordinate:");
  Serial.println(input_x_max);
  Serial.print("back lash maximum input y coordinate:");
  Serial.println(input_y_max);
  
  //  Inverse_Kinematics_Calculator(14.5,24.5);
  Inverse_Kinematics_Calculator(input_x_max,input_y_max);
  instbacklash_max_b = abs(out_boomangle);
  instbacklash_max_a = abs(out_armangle);
  Serial.print("back lash maximum angle boom:");
  Serial.println(instbacklash_max_b);
  Serial.print("back lash maximum angle arm:");
  Serial.println(instbacklash_max_a);

  Serial.println();
  Serial.print("------------------------------------\n");
  Serial.print("TOTAL Back Lash Angle BOOM: ");
  Serial.println(instbacklash_min_b + instbacklash_max_b);
  Serial.print("TOTAL Back Lash Angle ARM: ");
  Serial.println(instbacklash_min_a + instbacklash_max_a);
  Serial.print("------------------------------------");

  for(;;){}
}

void Foward_Kinematics_Action(double input_base,double input_boom,double input_arm)
{
  Foward_Kinematics_Calculator(input_base,input_boom,input_arm);
  anglemovementinset(input_base,input_boom,input_arm);
  currentpositionshower();
}

void Foward_Kinematics_Calculator(double angle_base, double angle_boom, double angle_arm)
{
  //double boom_L1 = 12.0;//boom의 길이
  //double arm_L3 = 12.0;//arm의 길이
  //double endeffectoroffset_wd = 3.0;//arm의 끝과 엔드이펙터 사이의 거리
  
  if(description == ON)
  {
    Serial.println();
    Serial.print("input base angle:");
    Serial.println(angle_base);
    Serial.print("input boom angle:");
    Serial.println(angle_boom);
    Serial.print("input arm angle:");
    Serial.println(angle_arm);
    delay(1000);
  }

  angle_arm = radians(angle_arm);//입력 각도 도 -> 라디안 변환
  angle_boom = radians(angle_boom);//입력 각도 도 -> 라디안 변환

  double x_boom = boom_L1*sin(angle_boom);//붐의 끝부분 평면 좌표 x축 = sin(붐 각도)*붐 길이
  double y_boom = boom_L1*cos(angle_boom)+y_offset;//붐의 끝부분 평면 좌표 y축 = cos(붐 각도)*붐 길이 + 본체 높이 오프셋 길이

  double x_arm = x_boom+(arm_L3*cos(angle_arm));//암의 끝부분 평면 좌표 x축 = cos(암각도)*암 길이 + 붐 x좌표
  double y_arm = y_boom-(arm_L3*sin(angle_arm));//암의 끝부분 평면 좌표 y축 = sin(암각도)*암 길이*-1 + 붐 y좌표()세타 3가 기준이라 반대로 이동

  double x_end = x_arm+endeffectoroffset_wd;//최종 좌표 + 엔드이펙터 오프셋 거리
  double y_end = y_arm;//최종 좌표

  if(description == ON)//설명
  {
    Serial.println();
    Serial.print("output x boom");
    Serial.println(x_boom);
    Serial.print("output y boom");
    Serial.println(y_boom);
    
    Serial.println();
    Serial.print("output x arm");
    Serial.println(x_arm);
    Serial.print("output y arm");
    Serial.println(y_arm);
    
    Serial.println();
    Serial.print("output x end:");
    Serial.println(x_end);
    Serial.print("output y end:");
    Serial.println(y_end);
  }
}

void Inverse_Kinematics_Action(double R_z,double Pos_x, double Pos_y)
{
  if(description == ON)
  {
    Serial.print("input base angle:");
    Serial.println(R_z);
    Serial.print("input Pos_x:");
    Serial.println(Pos_x);
    Serial.print("input Pos_y:");
    Serial.println(Pos_y);
    delay(2000);
  }
  Inverse_Kinematics_Calculator(Pos_x,Pos_y);
  anglemovementinset(R_z,out_boomangle,out_armangle);
}

void Inverse_Kinematics_Calculator(double P_x, double P_y)
{
  //역기구학 ppt에 있는 그림을 이용해서 보면 편함
  //double boom_L1 = 12.0;//boom의 길이
  //double arm_L3 = 12.0;//arm의 길이
  //double endeffectoroffset_wd = 3.0;//arm의 끝과 엔드이펙터 사이의 거리
  double boomangle_th1, armangle_th2, th21;
  P_y -= y_offset;//오프셋 제거
  double D = sqrt(pow((P_x) - endeffectoroffset_wd, 2) + pow(P_y, 2));//엔드이펙터 관절의 3차원 공간 위치
//  double posD = sqrt(pow(P_x, 2) + pow(P_y, 2));//엔드이펙터의 3차원 공간 위치
  //각도단위:라디안

  //th21값 계산(cos 2법칙 사용)
  th21 = acos((pow(boom_L1, 2) + pow(arm_L3, 2) - pow(D, 2)) / (2 * boom_L1 * arm_L3));
  //th1을 계산하기 위해 삼각형 p0,p1,p4에서 각p1-p0-p4의 각도값 계산
  double alpha = acos((pow(boom_L1, 2) + pow(D, 2) - pow(arm_L3, 2)) / (2 * boom_L1 * D));
  //th1을 계산하기 위해 삼각형 p0,p4_y,p4_x에서 각p4_y-p0-p4_x의 각도값 계산
  double psi = acos((pow(D, 2) + pow(P_x - endeffectoroffset_wd, 2) - pow(P_y, 2)) / (2 * D * (P_x - endeffectoroffset_wd)));

  //라디안->도 변환
  alpha = alpha * 180 / PI;
  psi = psi * 180 / PI;
  th21 = th21 * 180 / PI;//붐 암 사이 각
  
  if (P_y >= 0) //만약 엔드이펙터의 높이가 boom,arm 모터의 중심보다 위에 있을경우
    boomangle_th1 = alpha + psi; // 붐 각도
  else//만약 엔드이펙터의 높이가 boom,arm 모터의 중심보다 아래에 있을경우
    boomangle_th1 = alpha - psi; //붐 각도

  armangle_th2 = th21 + boomangle_th1; //암 모터 각도

  out_boomangle = (-1*boomangle_th1)+90;//오프셋 제외 최종 각도 붐
  out_armangle = (-1*armangle_th2)+180;//오프셋 제외 최종 각도 암

  if(description == ON)
  {
    Serial.print("D:");
    Serial.println(D);
    Serial.print("between boom & arm(th21):");
    Serial.println(th21);
    Serial.print("boom angle(th1):");
    Serial.println(out_boomangle);
    Serial.print("arm angle(th2):");
    Serial.println(out_armangle);
    Serial.println();
  }
}

void rotationmovementinsert(long base,long boom,long arm)
{
  positions[robot_position_base] = base;
  positions[robot_position_arm] = arm;
  positions[robot_position_boom] = boom;
  steppers.moveTo(positions); //포지션 입력
  steppers.runSpeedToPosition(); //각각 동작
}

void anglemovementinset(double angle_base, double angle_boom, double angle_arm)
{
  double instantbo, instantba, instantar;
  instantba = (angle_base*smallgearstep*microstep*normgear/360);
  instantbo = (planetarygear*angle_boom*smallgearstep*microstep*normgear/360);
  instantar = (planetarygear*angle_arm*smallgearstep*microstep*normgear/360);
  rotationmovementinsert((long)instantba, (long)instantbo, (long)instantar);
}

void currentpositionshower()
{
  long instantshower;

  instantshower = base.currentPosition();
  baseangle_current = (double)instantshower*360/(smallgearstep*microstep*normgear);
  Serial.print("\nangle current base:");
  Serial.println(baseangle_current);
  
  instantshower = boom.currentPosition();
  boomangle_current = (double)instantshower*360/(smallgearstep*microstep*planetarygear*normgear);
  Serial.print("angle current boom:");
  Serial.println(boomangle_current);

  instantshower = arm.currentPosition();
  armangle_current = (double)instantshower*360/(smallgearstep*microstep*planetarygear*normgear);
  Serial.print("angle current arm:");
  Serial.println(armangle_current);
}

void manualcontroller3()//button
{
  int x,y,z,g,adder = 10, tstate = OFF;//tstate means enable threshhold
  int xf = digitalRead(xbuf);
  int xb = digitalRead(xbub);
  int yf = digitalRead(ybuf);
  int yb = digitalRead(ybub);
  int zf = digitalRead(zbuf);
  int zb = digitalRead(zbub);
  int gf = digitalRead(gbuf);
  int gb = digitalRead(gbub);

  if((xf == tstate)&&(xb != tstate)) x = maxval;
  else if((xf != tstate)&&(xb == tstate)) x = minval;
  else x = midval;

  if((yf == tstate)&&(yb != tstate)) y = maxval;
  else if((yf != tstate)&&(yb == tstate)) y = minval;
  else y = midval;

  if((zf == tstate)&&(zb != tstate)) z = maxval;
  else if((zf != tstate)&&(zb == tstate)) z = minval;
  else z = midval;

  if(x >= maxval) positions[robot_position_arm] -= adder;
  else if(x <= minval) positions[robot_position_arm] += adder;
  else{}

  if(y <= minval) positions[robot_position_boom] += adder;
  else if(y >= maxval) positions[robot_position_boom] -= adder;
  else{}

  if(z <= minval) positions[robot_position_base] += adder;
  else if(z >= maxval) positions[robot_position_base] -= adder;
  else{}

  if((gf == tstate)&&(gb != tstate)) g = maxval;
  else if((gf != tstate)&&(gb == tstate)) g = minval;
  else g = midval;
  
  if(g <= minval) positions[robot_position_base] += adder;
  else if(g >= maxval) positions[robot_position_base] -= adder;
  else{}

  steppers.moveTo(positions); //포지션 입력
  steppers.runSpeedToPosition(); //각각 동작
}

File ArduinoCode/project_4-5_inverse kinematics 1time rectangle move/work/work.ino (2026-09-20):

/*

패치노트
  
  13. 설명 모드 추가, on off 추가
  12. 관절별 포지션 주소 지정 오류 수정 - 1번 모터가 돌아야 하는데 2번 모터가 돈다? = position 배열 숫자 수정 할것
  11. 모드 변경 버튼 조이스틱 통합
  10. 역기구학 구현
  09. 정기구학 구현 및 중도 오차 수정
  08. 아두이노 메가로 변경 및 버튼방식으로 변경
  07. 모드 설정 및 조이스틱 무브먼트 개선 = 시작과 동시에 조이스틱 입력시 모드전환
  06. 각도 입력 전 초기 위치 설정
  05. 감속기어 부착 버전 각도 입력 및 동시 도착
  04. 각 모터별 각도 입력 및 동시 도착
  03. 조이스틱 무브먼트 속도 개선, 설정 가능
  02. 동시동작 동시 도착
  01. 조이스틱 무브먼트

*/

/*
 * cnc구조 관련 링크
 * http://john-home.iptime.org:8085/xe/index.php?mid=board_jalN13&document_srl=1060
 * 아두이노 cnc쉴드 써서 제작 xyz라고 쓰여진데 있어서 하나 다른데만 안넣으면됨
 * z가 베이스
 * y가 링크1 암
 * x가 링크2 붐
 * a4988 드라이버 사용
 * 핀맵은 하단부에 적어둠
 * accelstepper, multistepper 라이브러리 같이쓰기
 * d8 enable 기능 gnd 동작이라서 스위치 연결하면 전원 항시 연결에 동작 활성화 비활성화 할수있음
 * a0123에 조이스틱 연결
 * d22~29에 스위치 연결
 * 마이크로 스텝 활성화시 점퍼캡 사용할 것
 * 
 * 마이크로 스텝
 * 분주비 16:1
 * 감속기어 비율 5:1
 * 작은 기어 회전에 걸리는 풀 스텝 수 200
 * 큰기어와 작은 기어간 기어비 9:32 - 711
 * NEMA 17급 바이폴라 방식 마이크로스텝 구동
 */

/*

multistepper


//////%%%%%%%%%%%%%%%%%%%%%%%%%%%%%%%%%%%%%%%%%%%%%%%%%%%%%%%%%%%%%%%%%%%%%%%%%%%%%%%%%%%%%%%%%%%%%%%%%
addStepper (AccelStepper &stepper)
//////%%%%%%%%%%%%%%%%%%%%%%%%%%%%%%%%%%%%%%%%%%%%%%%%%%%%%%%%%%%%%%%%%%%%%%%%%%%%%%%%%%%%%%%%%%%%%%%%%
    Add a stepper to the set of managed steppers There is an upper limit of MULTISTEPPER_MAX_STEPPERS = 10 to the number of steppers that can be managed
    Parameters [in]  stepper Reference to a stepper to add to the managed list
    
    관리되는 스테퍼 세트에 스테퍼 추가 관리 가능한 스테퍼 수에 MISTEPER_MAX_STEPPER = 10개의 상한이 있습니다
    매개변수 [in] stepper 관리 목록에 추가할 stepper 참조
//////%%%%%%%%%%%%%%%%%%%%%%%%%%%%%%%%%%%%%%%%%%%%%%%%%%%%%%%%%%%%%%%%%%%%%%%%%%%%%%%%%%%%%%%%%%%%%%%%%
moveTo (long absolute[])
//////%%%%%%%%%%%%%%%%%%%%%%%%%%%%%%%%%%%%%%%%%%%%%%%%%%%%%%%%%%%%%%%%%%%%%%%%%%%%%%%%%%%%%%%%%%%%%%%%%
    Set the target positions of all managed steppers according to a coordinate array. New speeds will be
    computed for each stepper so they will all arrive at their respective targets at very close to
    the same time.
    Parameters [in]  absolute  An array of desired absolute stepper positions. absolute[0] will
    be used to set the absolute position of the first stepper added by addStepper() etc. The array
    must be at least as long as the number of steppers that have been added by addStepper, else results
    are undefined.
    
    좌표 배열에 따라 관리되는 모든 스텝의 목표 위치를 설정합니다. 각 스텝마다 새로운 속도가 계산되어 각 스텝이 거의 동시에
    각 목표에 도달합니다.
    매개변수 absolute [in] 원하는 절대 스테퍼 위치의 배열입니다. absolute [0]은 addStepper() 등에 의해 추가된
    첫 번째 스테퍼의 절대 위치를 설정하는 데 사용됩니다. 배열은 적어도 addStepper에 의해 추가된 스테퍼의 수만큼 길어야 하며,
    그 외의 결과는 정의되지 않습니다. 배열을 먼저 정하고 이후에 함수 호출하면 지정된 배열에따라 각자 위치가 각 스텝마다 지정
    이후 동작
//////%%%%%%%%%%%%%%%%%%%%%%%%%%%%%%%%%%%%%%%%%%%%%%%%%%%%%%%%%%%%%%%%%%%%%%%%%%%%%%%%%%%%%%%%%%%%%%%%%
run ()
//////%%%%%%%%%%%%%%%%%%%%%%%%%%%%%%%%%%%%%%%%%%%%%%%%%%%%%%%%%%%%%%%%%%%%%%%%%%%%%%%%%%%%%%%%%%%%%%%%%
    Calls runSpeed() on all the managed steppers that have not acheived their target position.
    Returns true if any stepper is still in the process of running to its target position.
    
    호출은 목표 위치를 달성하지 못한 모든 관리되는 스텝에서 Speed()를 실행합니다.
    반환 스텝퍼가 아직 목표 위치로 실행 중인 경우 true입니다.
//////%%%%%%%%%%%%%%%%%%%%%%%%%%%%%%%%%%%%%%%%%%%%%%%%%%%%%%%%%%%%%%%%%%%%%%%%%%%%%%%%%%%%%%%%%%%%%%%%%
runSpeedToPosition ()
//////%%%%%%%%%%%%%%%%%%%%%%%%%%%%%%%%%%%%%%%%%%%%%%%%%%%%%%%%%%%%%%%%%%%%%%%%%%%%%%%%%%%%%%%%%%%%%%%%%
    Runs all managed steppers until they acheived their target position. Blocks until all that position is acheived. If you dont want blocking consider using run() instead.
    
    목표 위치를 달성할 때까지 관리되는 모든 스텝을 실행합니다. 해당 위치가 모두 달성될 때까지 차단합니다. 차단을 원하지 않는다면 대신 run()을 사용하는 것을 고려하십시오.
//////%%%%%%%%%%%%%%%%%%%%%%%%%%%%%%%%%%%%%%%%%%%%%%%%%%%%%%%%%%%%%%%%%%%%%%%%%%%%%%%%%%%%%%%%%%%%%%%%%


accel stepper


////////
//설정
////////

//////%%%%%%%%%%%%%%%%%%%%%%%%%%%%%%%%%%%%%%%%%%%%%%%%%%%%%%%%%%%%%%%%%%%%%%%%%%%%%%%%%%%%%%%%%%%%%%%%%
setMaxSpeed(float speed)
//////%%%%%%%%%%%%%%%%%%%%%%%%%%%%%%%%%%%%%%%%%%%%%%%%%%%%%%%%%%%%%%%%%%%%%%%%%%%%%%%%%%%%%%%%%%%%%%%%%
    Sets the maximum permitted speed. The run() function will accelerate up to the speed set by
    this function. Caution: the maximum speed achievable depends on your processor and clock speed.
    The default maxSpeed is 1.0 steps per second.
    Parameters [in]  speed The desired maximum speed in steps per second. Must be > 0. Caution: Speeds
    that exceed the maximum speed supported by the processor may Result in non-linear accelerations and
    decelerations.
    
    허용되는 최대 속도를 설정합니다. run() 기능은 이 기능에 의해 설정된 속도까지 가속됩니다. 주의: 달성 가능한 최대 속도는
    프로세서와 클럭 속도에 따라 다릅니다. 기본 maxSpeed는 초당 1.0단계입니다.
    매개변수 [in] speed 원하는 최대 속도(초당 단계). 0 이상이어야 합니다. 주의: 프로세서가 지원하는 최대 속도를 초과하는
    속도는 비선형 가속 및 감속을 초래할 수 있습니다.

//////%%%%%%%%%%%%%%%%%%%%%%%%%%%%%%%%%%%%%%%%%%%%%%%%%%%%%%%%%%%%%%%%%%%%%%%%%%%%%%%%%%%%%%%%%%%%%%%%%
setAcceleration(float acceleration)
//////%%%%%%%%%%%%%%%%%%%%%%%%%%%%%%%%%%%%%%%%%%%%%%%%%%%%%%%%%%%%%%%%%%%%%%%%%%%%%%%%%%%%%%%%%%%%%%%%%
    Sets the acceleration/deceleration rate.
    Parameters [in]  acceleration  The desired acceleration in steps per second per second. Must be > 0.0.
    This is an expensive call since it requires a square root to be calculated. Dont call more 
    of then than needed
    
    가속/감속 속도를 설정합니다.
    매개변수 [in] 가속도 초당 단계별 원하는 가속도. > 0.0이어야 합니다. 계산하려면 제곱근이 필요하기 때문에 값비싼
    호출입니다. 필요한 것보다 더 많이 호출하지 마십시오

//////%%%%%%%%%%%%%%%%%%%%%%%%%%%%%%%%%%%%%%%%%%%%%%%%%%%%%%%%%%%%%%%%%%%%%%%%%%%%%%%%%%%%%%%%%%%%%%%%%
setSpeed(float speed)
//////%%%%%%%%%%%%%%%%%%%%%%%%%%%%%%%%%%%%%%%%%%%%%%%%%%%%%%%%%%%%%%%%%%%%%%%%%%%%%%%%%%%%%%%%%%%%%%%%%
    Sets the desired constant speed for use with runSpeed().
    Parameters [in]  speed The desired constant speed in steps per second. Positive is clockwise.
    Speeds of more than 1000 steps per second are unreliable. Very slow speeds may be set
    (eg 0.00027777 for once per hour, approximately. Speed accuracy depends on the Arduino crystal.
    Jitter depends on how frequently you call the runSpeed() function. The speed will be limited by
    the current value of setMaxSpeed()

    runSpeed()와 함께 사용할 원하는 일정 속도를 설정합니다.
    매개변수 speed 초당 원하는 일정한 속도(단계)입니다. 양수는 시계 방향입니다. 초당 1000보 이상의 속도는
    신뢰할 수 없습니다. 매우 느린 속도가 설정될 수 있습니다(예: 대략 한 시간에 한 번 0.00027777). 속도 정확도는
    아두이노 크리스탈에 달려 있습니다. 지터는 runSpeed() 함수를 얼마나 자주 부르는지에 따라 달라집니다.
    속도는 setMaxSpeed()의 현재 값에 의해 제한됩니다
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

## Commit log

2026-09-20 up load arduino code and documents
    [로봇팔제작BOM.xlsx]
2026-09-20 Update gitignore and add CAD/STL files
    [683zz 베어링.STEP, 가이드.STEP, 기어_모터.STEP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]
2026-09-20 Add CAD and STL files
    [[ARM][1pcs] GearRotate_0.01mmTolerance 기어_바디.stl, [ARM][1pcs] baseRing 바디_접지링.stl, [ARM][1pcs] base_w_hole 바디_메인바디.stl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]

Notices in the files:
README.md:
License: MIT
